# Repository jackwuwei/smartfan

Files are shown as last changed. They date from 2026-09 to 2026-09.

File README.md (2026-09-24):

# 19" 2U Smart Temperature-Controlled Rack Fan (DIY)

**English** | [简体中文](README.zh-CN.md)

A 19-inch 2U rack-mount fan panel for network/server cabinets: three 80mm PWM fans automatically adjust their speed based on the temperature inside the cabinet. **The temperature control loop runs on the Arduino, so cooling keeps working even when the network is down.** A front-panel OLED + rotary knob provide local control, and WiFi/MQTT connects it to Home Assistant, which can in turn bridge it to Apple HomeKit. The panel is 3D printed, and every module connects **directly to the Arduino** with dupont wires (no soldering, no resistors).

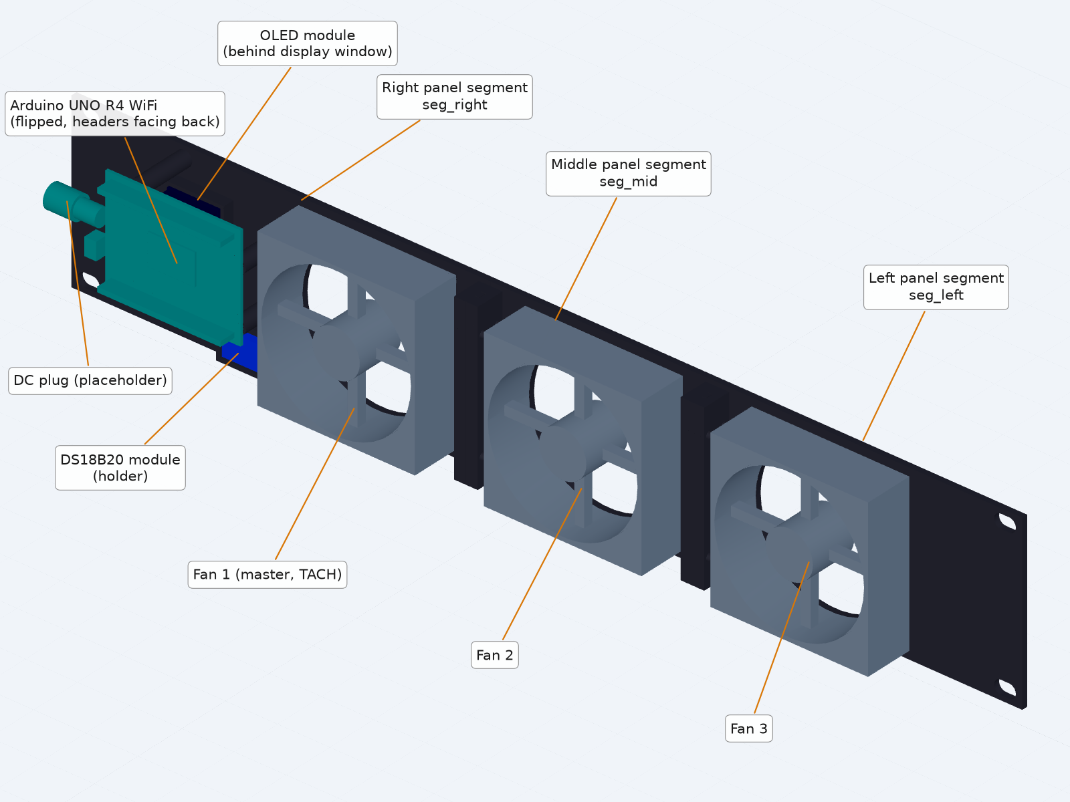
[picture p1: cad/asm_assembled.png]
Assembled


### Photos

<p align="center">
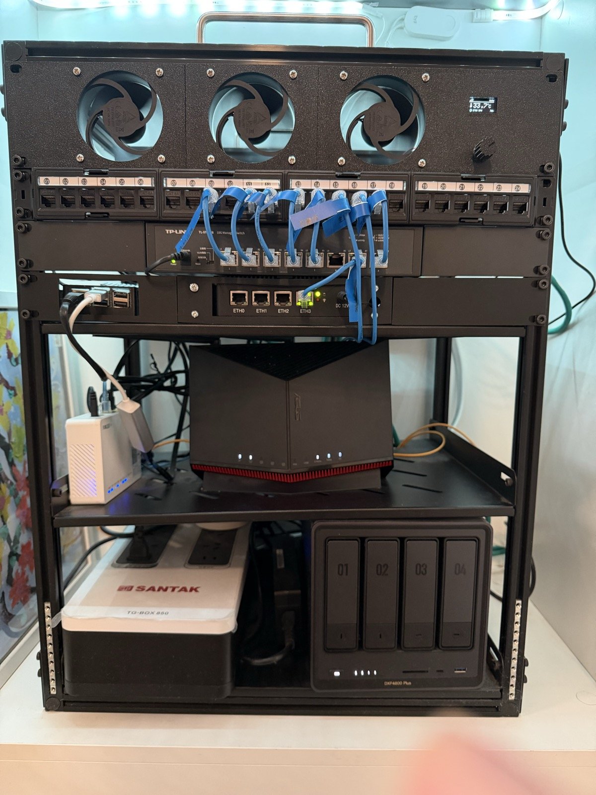
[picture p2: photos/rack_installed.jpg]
Installed at the top of a network cabinet
  
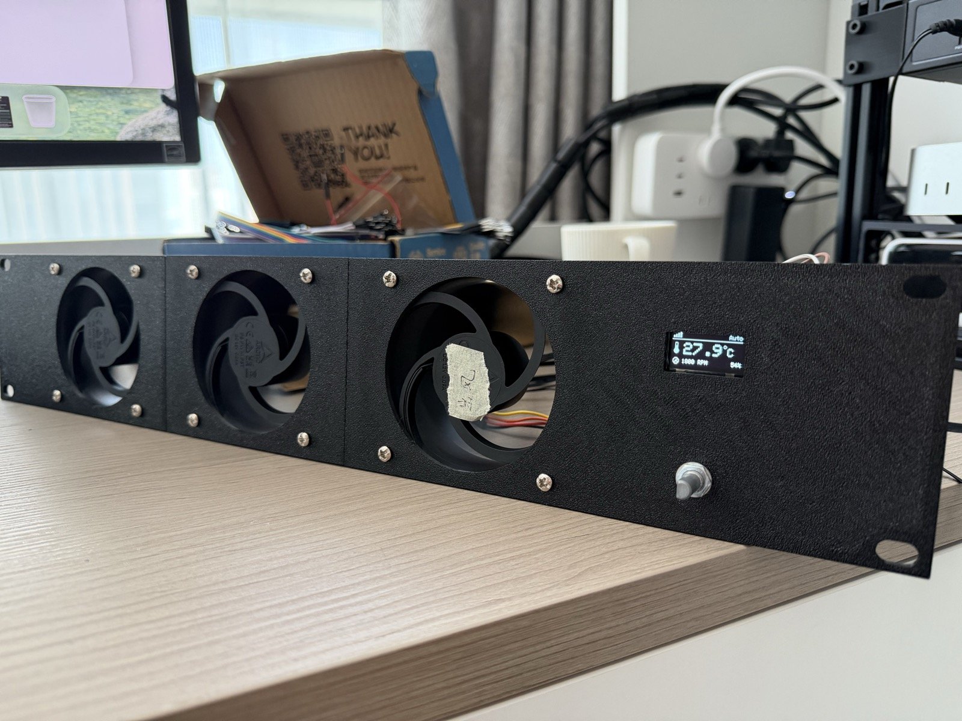
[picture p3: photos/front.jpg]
Front panel: 3 fans, OLED and knob
  
</p>
<p align="center"><i>Left: installed at the top of a home network cabinet. Right: front panel — OLED shows temperature, mode, master fan RPM and duty.</i></p>

<p align="center">
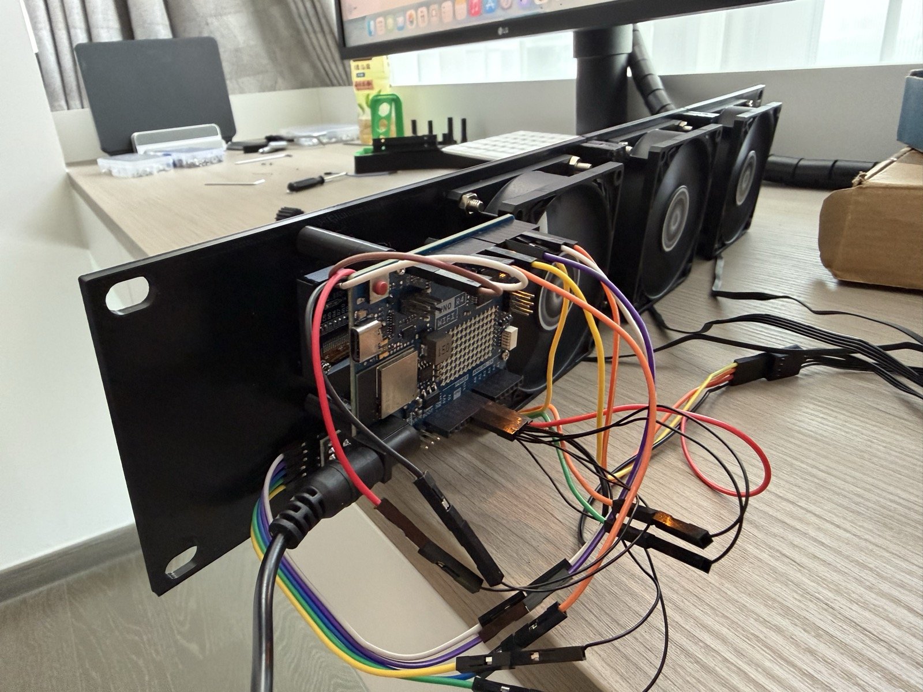
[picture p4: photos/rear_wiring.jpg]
Rear view: flipped Arduino with dupont wires plugged straight into the headers
  
</p>
<p align="center"><i>Rear: the Arduino is mounted flipped so every module plugs straight into its headers with dupont wires (no breadboard, no soldering).</i></p>

---

## 1. Bill of Materials

### 1.1 Electronics

| Part | Spec | Qty | Approx. price (US) | Link (US) |
|---|---|---|---|---|
| Arduino UNO R4 WiFi | Must be the **WiFi** version (ABX00087) | 1 | $27.50 | [Amazon](https://www.amazon.com/Arduino-UNO-WiFi-ABX00087-Bluetooth/dp/B0C8V88Z9D) |
| Arctic P8 PWM PST fan | 8025, 4-pin PWM, 0.14A, stops at 0% PWM (**not** the "CO" variant) | 3 | ~$9 each | [Amazon](https://www.amazon.com/ARCTIC-P8-PWM-PST-Pressure-optimised/dp/B07WWKF96F) |
| 4-pin male-to-female fan extension cable | 2.54mm, ~300mm / 12" (master fan → Arduino headers) | 1 | ~$8 (2-pack) | [Amazon](https://www.amazon.com/Cable-Matters-2-Pack-4-Pin-Extension/dp/B07FK5H679) |
| 12V DC power adapter | 12V 2A, 5.5×2.1mm, center positive | 1 | ~$9 | [Amazon](https://www.amazon.com/Power-Supply-5-5x2-1mm-Plug-White/dp/B09J267K2P) |
| DS18B20 temperature module | Onboard 4.7k pull-up | 1 | ~$7 (3-pack) | [Amazon](https://www.amazon.com/DS18B20-Temperature-Measurement-Arduino-Starter/dp/B0786CZCYJ) |
| 0.96" OLED | SSD1306, 128×64, 4-pin I2C | 1 | ~$7 | [Amazon](https://www.amazon.com/HiLetgo-Adafruit-Beaglebones-Raspberry-Optional/dp/B076DYCWC8) |
| KY-040 rotary encoder | Threaded bushing + nut + push button | 1 | ~$9 (8-pack) | [Amazon](https://www.amazon.com/WGCD-KY-040-Degree-Encoder-Arduino/dp/B07B68H6R8) |
| **1-to-3 dupont splitter cable** | 2.54mm, one male end → three female ends; one for 5V, one for GND | 2 | ~$7 (pack) | [Amazon search](https://www.amazon.com/s?k=dupont+jumper+wire+splitter+1+male+to+3+female) |
| Dupont wires | 20cm, M-F / M-M / F-F assortment, for signals | several | ~$7 (120 pcs) | [Amazon](https://www.amazon.com/Elegoo-EL-CP-004-Multicolored-Breadboard-arduino/dp/B01EV70C78) |

> Total ≈ US$110 (Amazon prices vary; most small parts only come in multi-packs). Three fans at full speed draw about 0.4A @ 12V and the whole unit ~0.7A, so a 12V 2A adapter is plenty. The links are examples — any part matching the spec column works. Buying in China? [README.zh-CN.md](README.zh-CN.md) lists Taobao links.
>
> ⚠ The printed mounts were sized on the original (Taobao) modules: DS18B20 PCB 28.2×13mm, OLED M2 holes 21×21.5mm apart, encoder bushing Ø6.8mm. Module footprints vary between sellers — check yours, and adjust `SENS_*`/`MOD_*`, `OLED_HOLE_*` and `ENC_HOLE_D` in `cad/rack_fan_2u.py` if needed (see `cad/README.md`).

### 1.2 Printed parts (PETG, Bambu P1S)

The 482.6mm panel is wider than the 256mm print bed, so it is split into 3 segments joined with M3 screws. STLs are in `cad/stl/`.

| Part | Contents | Orientation |
|---|---|---|
| `seg_left.stl` (155mm) | Fan 3 + left rack ear | Front face down |
| `seg_mid.stl` (117mm) | Fan 2 | Front face down |
| `seg_right.stl` (215mm) | Fan 1 (master) + control area (OLED window, knob hole, Arduino standoffs, DS18B20 holder) + right rack ear | Front face down |
| `encoder_knob.stl` | Knob (D-shaped bore, press-fits a 6mm shaft) | Top face down |

Print settings: 0.2mm layers / 4 walls / 30–40% gyroid, essentially no supports. PLA softens with heat — use PETG.

### 1.3 Fasteners

| Use | Spec | Qty |
|---|---|---|
| Joining segments | M3×16 + nut | 8 |
| Fans → panel | M4 | 12 |
| Arduino → standoffs | M2×8 self-tapping | 4 |
| OLED → standoffs | M2×6 self-tapping | 4 |
| DS18B20 → holder | M2.5×6 self-tapping | 1 |
| Encoder | Nut supplied with the module | 1 |
| Rack mounting | M6 cage nuts + screws | 4 |
| Cable strain relief | Zip ties | several |

---

## 2. Schematic

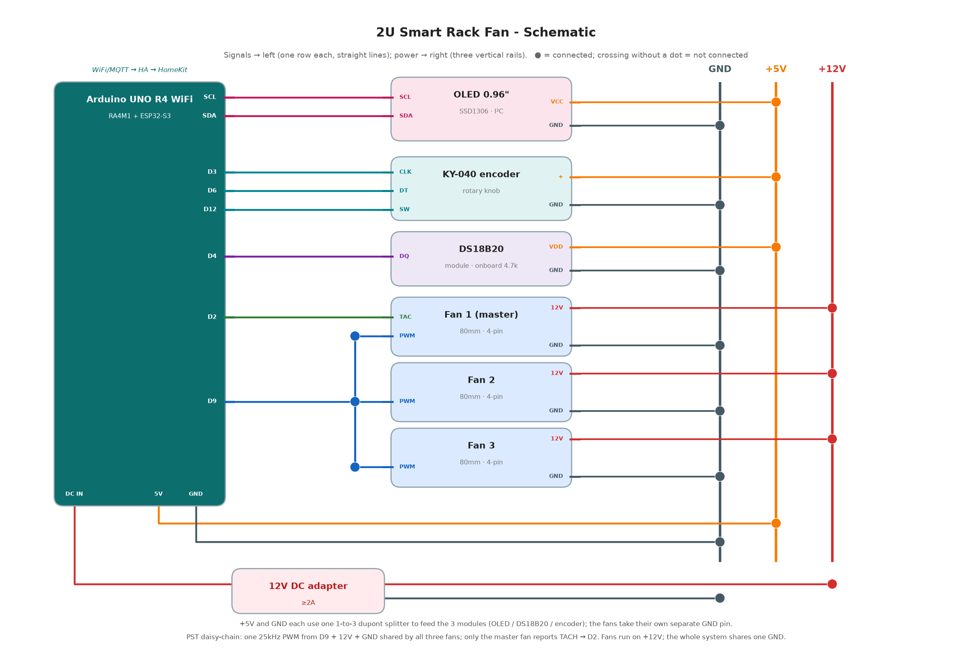
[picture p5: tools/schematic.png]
Wiring schematic


> Signal lines run left to the Arduino; power lines run right to the three power rails (GND / +5V / +12V). ● = connected; a crossing without a dot = not connected.

**Pin assignment (UNO R4 WiFi)**

| Function | Pin | Notes |
|---|---|---|
| Fan PWM | **D9** | 25kHz (core `PwmOut`), drives all 3 fans through the PST daisy chain |
| Fan TACH | **D2** | Master fan only; `INPUT_PULLUP`, interrupt-counted (2 pulses/rev) |
| DS18B20 | **D4** | 1-Wire, module has an onboard 4.7k pull-up |
| OLED | **SDA / SCL** | I2C, address 0x3C |
| KY-040 | **D3 / D6 / D12** | CLK / DT / SW, internal pull-ups; **CLK must be on D3** (on the R4 only D2/D3 support external interrupts, and D2 is taken by TACH) |
| Fan +12V | **VIN** | 12V enters through the onboard DC barrel jack and is taken straight from VIN |

---

## 3. Wiring

**Two 1-to-3 dupont splitters distribute power; everything else plugs straight into the Arduino headers.**

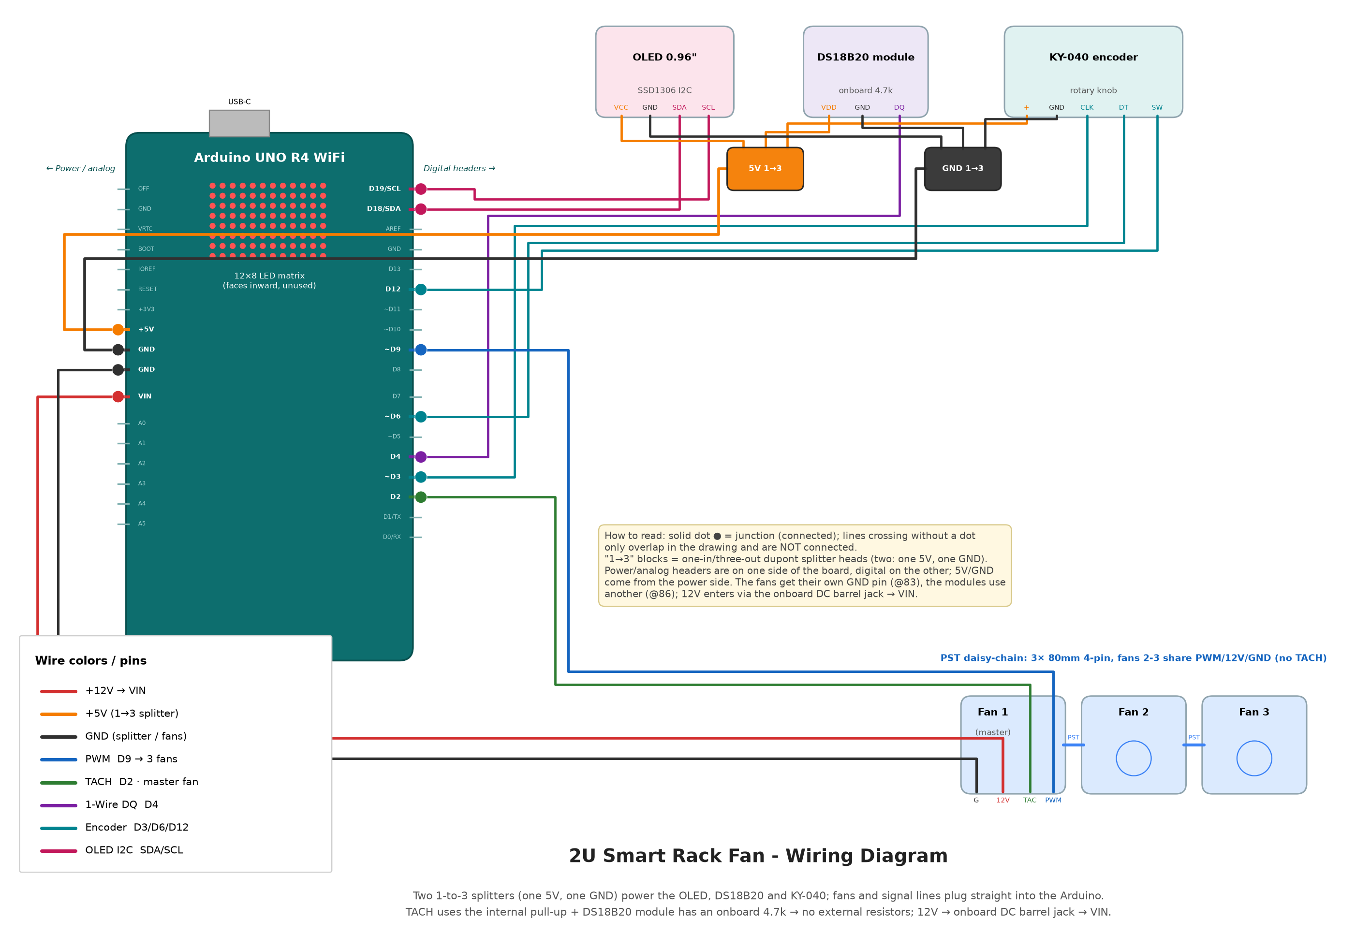
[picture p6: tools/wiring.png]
Wiring diagram


> Colors: red = +12V, orange = +5V, black = GND, blue = PWM, green = TACH, purple = 1-Wire, cyan = encoder, pink = I2C. The two small squares are the 5V / GND 1-to-3 splitters.

### 3.1 Connection table

| Arduino | Connects to | Wire |
|---|---|---|
| DC barrel jack | 12V adapter | — |
| **5V** | OLED VCC / DS18B20 VDD / KY-040 + | 1-to-3 splitter #1 |
| **GND** (pin ②) | OLED GND / DS18B20 GND / KY-040 GND | 1-to-3 splitter #2 |
| **VIN** | Master fan pin 2 (+12V) | 4-pin adapter cable |
| **GND** (pin ①) | Master fan pin 1 (GND) | 4-pin adapter cable |
| **D9** | Master fan pin 4 (PWM) | 4-pin adapter cable |
| **D2** | Master fan pin 3 (TACH) | 4-pin adapter cable |
| **SDA / SCL** | OLED SDA / SCL | Dupont wire |
| **D4** | DS18B20 DQ | Dupont wire |
| **D3 / D6 / D12** | KY-040 CLK / DT / SW | Dupont wire (swap CLK/DT if the rotation direction is reversed) |

- **PST daisy chain**: Fan 1 (master) → Fan 2 → Fan 3, chained through the male/female 4-pin connectors built into the fans. GND / +12V / PWM are shared along the chain; the two downstream fans don't report TACH, so only the master fan's speed can be measured.
- The fan ground and the module ground each use their own GND pin; they are common on the board.

### 3.2 4-pin fan connector pinout

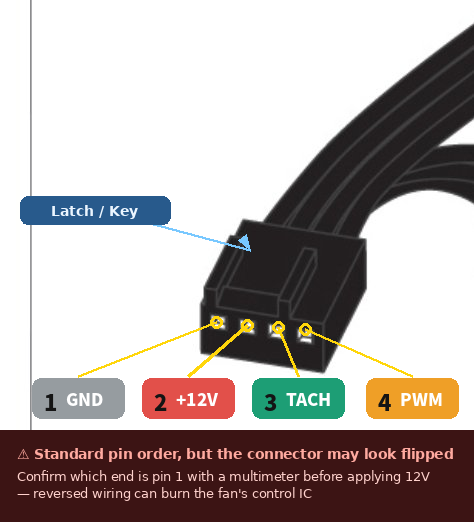
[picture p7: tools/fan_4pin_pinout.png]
4-pin fan pinout


| Pin | Signal | Connects to |
|---|---|---|
| 1 | GND | GND |
| 2 | +12V | VIN |
| 3 | TACH | D2 |
| 4 | PWM | D9 |

> ⚠ Locate pin 1 using the locking tab and confirm with a multimeter before powering up — plugging it in reversed can destroy the fan.

### 3.3 Pre-power-on checklist

- [ ] No short between VIN/GND or 5V/GND; the master fan's 4-pin cable is not reversed.
- [ ] All 3 leads of the 5V splitter go to module positive pins; all 3 leads of the GND splitter go to module grounds.
- [ ] First connect only the master fan and verify speed control and RPM reading, then chain on the other two.

---

## 4. Software Overview

Firmware: `firmware/smartfan/smartfan.ino` (single file, non-blocking main loop).

```mermaid
flowchart TD
    BOOT([Power on]) --> INIT["Init PWM / OLED / knob / TACH"]
    INIT --> RST{"Knob held ≥2s at boot?"}
    RST -->|Yes| CLR["Clear network config"]
    RST -->|No| LOAD
    CLR --> LOAD["Load EEPROM: setpoint / mode / manual %"]
    LOAD --> NET{"Network configured?"}
    NET -->|No| PORTAL["Provisioning portal<br/>Scan WiFi → start AP RackFan-Setup<br/>Show QR on OLED → fill web form → save & reboot"]
    NET -->|Yes| WIFI["Connect WiFi (non-blocking)"]
    WIFI --> LOOP

    subgraph LOOP["loop() main loop"]
        direction TB
        E["Every pass: read knob"]
        S["Every 1s: read temperature + compute RPM → control (compute duty → PWM) → check alarms"]
        D["Every 250ms: refresh OLED"]
        M["Every 2s: publish state over MQTT"]
        R["Every 5s: reconnect WiFi/MQTT if dropped"]
        P["HA command received → update settings and save to EEPROM"]
    end
```

> **Networking is an add-on**: if WiFi/MQTT/HA goes down, only reporting and remote control are affected — temperature sampling and fan control keep running.
>
> **Watchdog**: a ~5.5s hardware watchdog resets the board if the main loop (or the provisioning loop) ever hangs, e.g. the WiFi co-processor stops responding. After a watchdog reset the fans start at 100% and slew down to the curve, so even repeated resets keep the cabinet cooled.

### 4.1 Control algorithm

**Fan curve** (shifts with the setpoint Tset, default 35°C):

- `T ≤ Tset−10°C` → 20%; `T ≥ Tset+6°C` → 100%; linear in between
- With defaults: 25°C→20%, 30°C→45%, 35°C→70%, ≥41°C→100%
- Duty changes by at most 5% per second to avoid abrupt jumps

**Four modes**

| Mode | Duty |
|---|---|
| Auto | Follows the curve |
| Silent | Follows the curve, capped at 60% |
| Manual | Fixed manual value |
| Turbo | 100% |

**Safety (takes priority over the mode)**

- Sensor unreadable / out of range, or temperature ≥ 60°C → forced 100% + alarm
- Duty >25% but master fan <60 RPM → stall alarm
- Power off (turned off from HA) → 0%, fans stop. ⚠ Power off overrides the safety rules above: while off, the fans stay stopped even on over-temperature or sensor failure (the alarm is still raised and reported to HA)
- On alarm the whole OLED screen blinks

### 4.2 Knob and display

| Action | Effect |
|---|---|
| Rotate | Adjust setpoint (±1°C, 25–55); in Manual mode, adjust fan % (±5) |
| Short press | Cycle the display page: temperature → setpoint → fan % → mode (display only — what rotating adjusts depends on the mode, see above) |
| Long press (≥0.8s) | Change mode: Auto → Manual → Silent → Turbo |
| Hold 2s at power-on | Re-run WiFi provisioning |

OLED: top bar shows WiFi signal + mode, the middle shows the temperature in large digits, the bottom shows master fan RPM + duty. While turning the knob, the middle temporarily shows the value being adjusted.

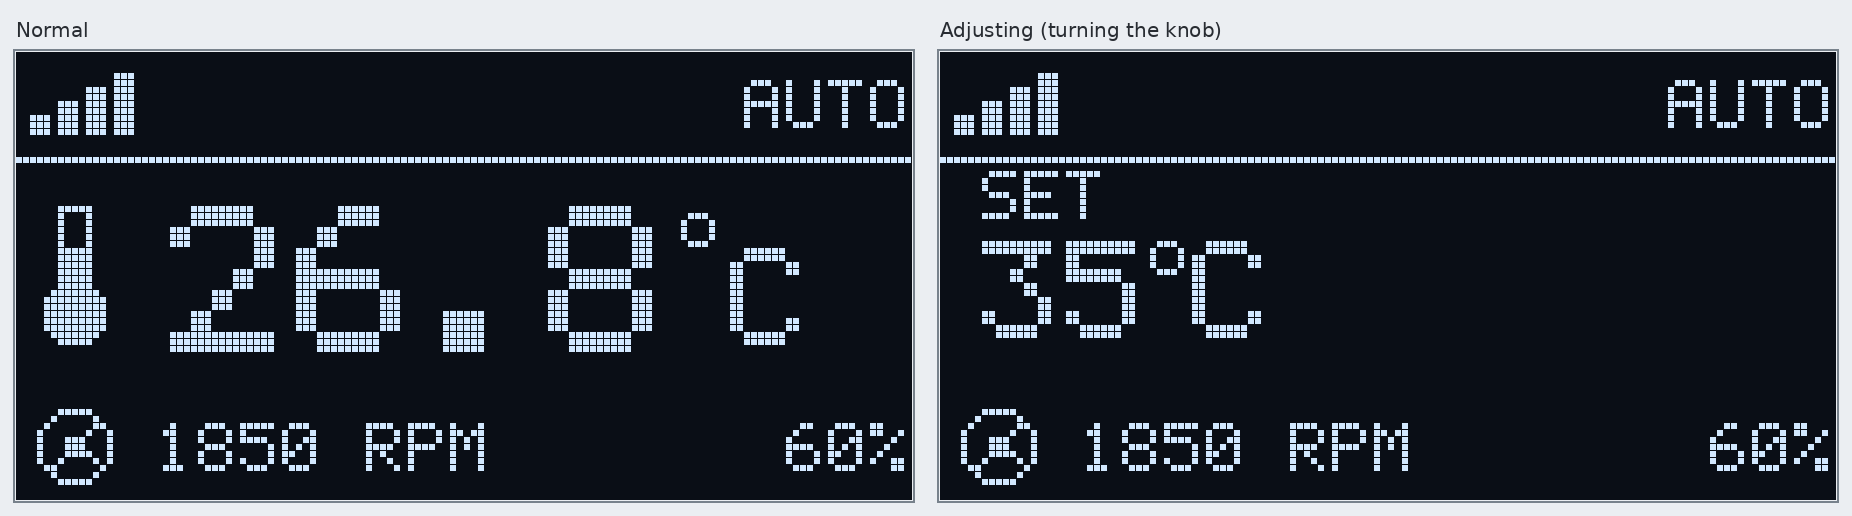
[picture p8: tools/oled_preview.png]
OLED layout


Setpoint, mode and manual % are stored in EEPROM (survive power loss) and sync both ways with HA.

### 4.3 WiFi provisioning

1. On first boot (or when holding the knob for 2s at power-on), the OLED shows a QR code.
2. Scan it with your phone to join the `RackFan-Setup` hotspot (password `configme123`). The setup page usually pops up automatically; if not, open `192.168.4.1`.
3. Pick your WiFi from the list (**2.4GHz only**) and enter its password, then the MQTT host/port/credentials and device ID (default `rackfan01`) → save, and the device reboots automatically.

Temperature control keeps running while the setup portal is open (the OLED just shows the QR code instead of the status screen).

> The setup hotspot password is a public default. It only matters while the portal is open, but anyone nearby could join during that window — change `AP_PASS` at the top of the `.ino` before flashing if that concerns you. WiFi/MQTT credentials are stored in the board's EEPROM, and MQTT runs unencrypted on port 1883, so keep the broker on a trusted LAN.

### 4.4 Home Assistant / HomeKit

1. In HA, install the **Mosquitto broker** and create an MQTT user (enter this user during provisioning), then add the **MQTT** integration (leave the discovery prefix as `homeassistant`).
2. Once the device is online, **Smart Rack Fan** appears automatically with: `climate` (thermostat + mode presets), `fan` (on/off + speed), `sensor` (temperature, RPM), `binary_sensor` (alarm).
3. Add the **HomeKit Bridge** integration and include the `climate` entity → pair it in the Apple Home app by scanning the code, and you can control it with Siri.

MQTT topics are `rackfan/<device ID>/<item>/state` (reports) and `.../<item>/set` (commands). Report-only items: `temp`, `rpm`, `action`, `alarm`, plus `rackfan/<device ID>/avail` (`online` / `offline`, retained; `offline` is the broker-published last-will, so HA shows the entities as unavailable when the device drops off); controllable items: `power`, `hvac/mode` (cool/off), `set` (target temperature 25–55), `mode` (Auto/Manual/Silent/Turbo), `pct` (manual %). For debugging, subscribe to `rackfan/rackfan01/#`. If you'd rather not use auto-discovery, configure it manually with `homeassistant/rack_fan.yaml`.

---

## 5. Assembly

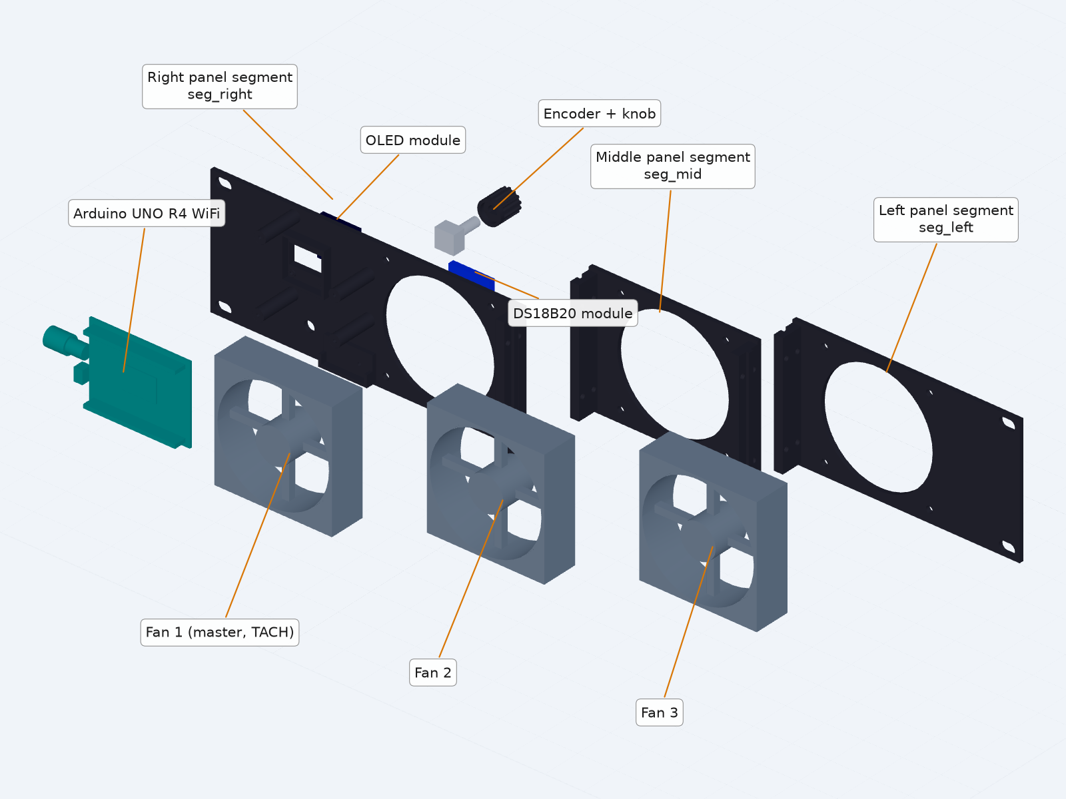
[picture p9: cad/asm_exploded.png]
Exploded view


1. **Join the panel**: slot the three segments together by their tongue-and-groove joints; 4 × M3×16 + nuts per seam.
2. **Mount the fans**: fans go behind the panel, fixed with M4 screws. This unit **exhausts air out of the cabinet**: the airflow arrow points forward (toward the panel), so the cabinet needs a cool-air intake elsewhere.
3. **Mount the OLED**: align the glass with the display window and screw it onto the four corner standoffs with 4 × M2×6 self-tapping screws, pins facing backward.
4. **Mount the Arduino**: 4 × M2×8 self-tapping screws into the standoffs. ⚠ **Component side / headers face backward** (so dupont wires fit), and **USB/DC ports face right** (toward the rack ear, so the 12V plug has room).
5. **Mount the encoder + DS18B20**: pass the encoder bushing through the panel hole, tighten with its nut, then press on the knob; slide the DS18B20 into its holder and fix it with 1 × M2.5 self-tapping screw.
6. **Wire it up**: follow Section 3; secure the adapter cable, splitters and power lead with zip ties.
7. **Rack it**: M6 screws through the oval slots on both sides. Plug in 12V and provision as in 4.3.

---

## 6. Flashing and Development

- **Flashing**: in the Arduino IDE install the `Arduino UNO R4 Boards` core, then the libraries `ArduinoMqttClient`, `ArduinoJson` (v6 or v7), `OneWire`, `DallasTemperature`, `Adafruit GFX Library`, `Adafruit SSD1306`, `QRCode` (Richard Moore). Close the Serial Monitor before uploading.
- Tunables at the top of the `.ino`: `DEBUG_NO_HW` must be 0 (1 = simulated temperature, for bench testing only); `USE_PWMOUT_25K` = 1 outputs 25kHz, 0 falls back to analogWrite (~490Hz, audible whine); `OLED_ADDR`; control parameters; `AP_PASS`.
- **Bring-up order**: provisioning → master fan speed control/RPM → chain all 3 fans → unplug the DS18B20 to verify forced 100% → knob/OLED → disconnect the network to verify it still follows the curve.
- **CAD**: `cad/rack_fan_2u.py` is the single source of parameters; see [cad/README.md](cad/README.md) for the parameter reference and build commands.
- **Regenerating images**: `python3 tools/gen_schematic.py` (schematic), `gen_breadboard.py` (wiring diagram), `gen_oled_preview.py` (OLED preview). Requires `matplotlib` and `Pillow`.

```
.
├── README.md                  This document
├── firmware/smartfan/         Firmware
├── homeassistant/             Manual HA YAML (fallback)
├── photos/                    Photos of the finished build
├── cad/                       Parametric CAD + STEP; stl/ holds the printable parts
└── tools/                     Scripts and images for the schematic / wiring diagram / OLED preview
```

## License

[MIT](LICENSE) — covers the firmware, scripts, CAD sources and printable models. Build and use at your own risk.

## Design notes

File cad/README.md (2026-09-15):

# CAD sources (build123d, parametric)

**English** | [简体中文](README.zh-CN.md)

The full assembly and every printed part are generated parametrically by these Python scripts. Change a parameter → regenerate → the STEP files (this directory) and STL files (`stl/`) update together.

## 1. File relationships

```
rack_fan_2u.py        main file: all parameters + geometry helpers + full assembly gen_step()
   ├─ seg_left.py     thin wrapper → make_segment() cuts the left segment    (no own parameters)
   ├─ seg_mid.py      thin wrapper → make_segment() cuts the middle segment  (no own parameters)
   ├─ seg_right.py    thin wrapper → make_segment() cuts the right segment   (no own parameters)
   └─ encoder_knob.py standalone knob part with its own parameters; imported into the assembly by the main file
```

- **Printed-part dimensions and hole positions → almost all live in the parameter block at the top of `rack_fan_2u.py`.** The 3 thin wrappers only "cut one piece out of the full assembly" and carry no parameters.
- Any change to `rack_fan_2u.py` means regenerating all 4 printed parts (they import it).
- Only the knob's shaft fit is tuned separately, in `encoder_knob.py`.

## 2. Coordinate system (Z-up)

Origin = **center of the panel front face**. `X` = width (+ is right), `Z` = height (+ is up), `Y` = depth (+Y points behind the panel).
CAD Viewer is Z-up as well. `rack_fan_2u.step` is the **full assembly** (including fan/Arduino placeholders), for viewing only — it is **not printed**.

## 3. How to generate

Each script exposes a `gen_step()` that returns a build123d shape. Run all commands from `cad/`.

### Option A: with the `cad` agent skill

If you use the `cad` agent skill (with its venv set up):

```bash
source ~/.agents/skills/cad/.venv/bin/activate
SKILL=~/.agents/skills/cad/scripts

# Full assembly (for viewing)
python $SKILL/step rack_fan_2u.py

# Individual printed parts: STEP (this directory) + STL (into stl/)
python $SKILL/step seg_right.py        --force --stl stl/seg_right.stl
python $SKILL/step seg_left.py         --force --stl stl/seg_left.stl
python $SKILL/step seg_mid.py          --force --stl stl/seg_mid.stl
python $SKILL/step encoder_knob.py     --force --stl stl/encoder_knob.stl
```

### Option B: plain build123d

```bash
pip install build123d
```

Then, from `cad/`:

```python
import importlib
from build123d import export_step, export_stl

# Printed parts: STEP + STL
for name in ["seg_left", "seg_mid", "seg_right", "encoder_knob"]:
    shape = importlib.import_module(name).gen_step()
    export_step(shape, f"{name}.step")
    export_stl(shape, f"stl/{name}.stl")

# Full assembly (for viewing only, no STL needed)
import rack_fan_2u
export_step(rack_fan_2u.gen_step(), "rack_fan_2u.step")
```

> After changing shared parameters in `rack_fan_2u.py`, **regenerate all 4 printed parts**; if you only changed `encoder_knob.py`, just regenerate the knob (and the assembly).

## 4. `rack_fan_2u.py` parameters (all at the top of the file, in mm)

### Panel / rack
| Parameter | Default | Meaning / effect of changing |
|---|---|---|
| `PANEL_W, PANEL_T, PANEL_H` | 482.6, 3.0, 88.1 | 19" 2U panel width / thickness / height (EIA-310; don't change width or height) |
| `RACK_HOLE_DX` | 465.1/2 | Half the distance between left and right rack hole centers |
| `RACK_HOLE_Z` | 38.1 | Rack hole Z per side (symmetric ±38.1) |
| `RACK_SLOT_LEN, RACK_SLOT_H` | 11.0, 7.0 | Rack oblong slot X length / Z height (length − height = ±2mm side-to-side play, M6) |

### Fans
| Parameter | Default | Meaning / effect of changing |
|---|---|---|
| `FAN` | 80.0 | Fan size (8025) |
| `FAN_BORE_D` | 76.0 | Panel air inlet cutout diameter |
| `FAN_HOLE_PITCH` | 71.5 | Square spacing of the 4 M4 screw holes |
| `FAN_HOLE_D` | 4.5 | M4 clearance hole diameter |
| `FAN_DEPTH` | 25.0 | Fan thickness (placeholder only) |
| `FAN_CX` | [-144, -29, 86] | **X centers of the 3 fans.** Changing this moves the whole layout; together with `CTRL_CX` it sets the 4 evenly spaced columns |

### Control column: OLED window / knob / Arduino / connectors
| Parameter | Default | Meaning / effect of changing |
|---|---|---|
| `CTRL_CX` | 174.0 | **Control column X center** (the OLED window is centered on it). Note that `ARD_CX`, `ENC_CX` and `SENS_CX` are set separately — update them as needed when changing `CTRL_CX` |
| `ARD_CX` | 165.0 | **Arduino X center** (9 left of `CTRL_CX`): clearance for the DC jack/plug on the right; **any further left hits fan 1 (master)** (left posts ≈ X133, fan 1 right edge X126) |
| `ARD_CZ` | 14.0 | Arduino Z center (mounted flipped; onboard matrix faces inward and is unused, so no window alignment needed) |
| `OLED_CZ` | 14.0 | OLED window + module Z center |
| `OLED_WIN_W, OLED_WIN_H` | 25.0, 13.5 | OLED window in the panel; window center `OLED_WIN_CZ` = `OLED_CZ` + 0.75 |
| `OLED_MOD_W/_T/_H` | 26.0, 5.0, 26.0 | OLED module PCB outline (placeholder + sets the size of the rear pocket) |
| `OLED_PIN_H` | 8.5 | OLED 4-pin header protrusion (wires exit toward +Y) |
| `OLED_HOLE_DX` | 10.5 | X of the OLED corner holes relative to board center (±10.5; measured 25×25 board, 2.0 from each side) |
| `OLED_HOLE_DZ_TOP, _BOT` | 11.0, -10.5 | Z of top/bottom holes relative to board center (top 1.5 from top edge, bottom 2.0 from bottom edge) |
| `OLED_STANDOFF_H` | 2.0 | Height of the 4 short OLED posts (glass close to the window; tune to the actual glass height) |
| `OLED_STANDOFF_D` | 4.5 | OLED post outer diameter (M2) |
| `OLED_PILOT_D, OLED_PILOT_DEPTH` | 2.0, 4.0 | M2 self-tap pilot hole in the OLED post tops (may extend into the panel) |
| `ENC_CX, ENC_CZ` | 174.0, -26.0 | Encoder (knob/shaft) center, below the OLED window (moved down so the KY-040 pins clear the Arduino posts) |
| `ENC_HOLE_D` | 7.2 | Clearance hole ⌀7.2 for the encoder's threaded bushing |
| `ARD_W, ARD_T, ARD_L` | 68.6, 1.6, 53.4 | UNO R4 board width / thickness / length (placeholder) |
| `ARD_STANDOFF_H` | 28.0 | Arduino post height: flipped, the solder side faces the panel and must clear the OLED module + pins/wires in front |
| `HDR_H` | 8.5 | Arduino female header height (faces backward when flipped; placeholder, sets the dupont-wire clearance) |
| `STANDOFF_D` | 8.0 | Arduino post outer diameter Ø8 |
| `ARD_PILOT_D, ARD_PILOT_DEPTH` | 2.0, 8.0 | **M2 self-tap pilot holes in the tops** of the 4 short Arduino posts (board holes Ø3.2 take M2) |
| `ARD_HOLES` | see file | **(x, z) of the 4 mounting holes relative to board center.** Currently the **flipped** version (component side / female headers toward +Y at the rear, USB/DC short edge still toward +X). If you change the board orientation, the hole positions must flip with it (see §6). |
| `DC_JACK_D/LEN`, `DC_PLUG_D/LEN`, `USB_*`, `CONN_DC_Z/USB_Z` | see file | Placeholders for the DC barrel jack / representative straight plug / USB-C on the port edge, **only for checking plug clearance** — not structural |

> ⚠️ **Two key orientation constraints**: (1) component side / female headers face **+Y (rear)** — otherwise there is no room for dupont wires; (2) the USB/DC short edge faces **+X (toward the panel's open right end)** — otherwise the DC plug can't go straight into the barrel jack. See the root `README.md` → "Assembly", step 4.

> 🔌 **Direct wiring**: the OLED/DS18B20/KY-040 connect directly to the Arduino via two 1-to-3 dupont splitter cables (one for 5V, one for GND); there is no breakout board, tray or other carrier on the panel.

### Sensor / cabling
| Parameter | Default | Meaning |
|---|---|---|
| `SENS_CX, SENS_CZ` | 145.0, -33.0 | DS18B20 module cradle center (free space below the control area) |
| `MOD_W, MOD_H, MOD_T` | 28.2, 13.0, 4.0 | DS18B20 PCB module outline (measured; sets the cradle size) |
| `SENS_HOLE_DX` | 6.4 | Sensor board mounting hole distance from the left edge (vertically centered); M2.5 self-tap hole in the cradle base |
| `SENS_PILOT_D` | 2.2 | M2.5 self-tap pilot hole diameter |
| `VENT_ZS` | () | Control-area vent slots (empty = none; if added, keep clear of the ⌀16 knob at `ENC_CZ`) |
| `CABLE_TIE_X` | () | Cable-tie holes along the bottom edge (empty = none) |

### Segmented printing + M3 joints
| Parameter | Default | Meaning / effect of changing |
|---|---|---|
| `SEAM1, SEAM2` | -86.5, 28.5 | **X of the two seams.** Must fall in the solid area between fans, and each segment must be ≤ 256 wide (P1S bed) |
| `WALL_T` | 6.0 | Joint wall thickness per side (X) |
| `WALL_Y0, WALL_Y1` | 3.0, 18.0 | Y range of the joint walls behind the panel (15mm deep) |
| `WALL_Z` | 84.0 | Joint wall height (nearly full height) |
| `GROOVE_W, GROOVE_D` | 4.0, 2.2 | Alignment tongue/groove width in Y / depth in X (tongue clearance is applied automatically) |
| `BOLT_YS, BOLT_ZS` | (6,15), (-28,28) | Y and Z positions of the 4 M3 bolts per seam (two rows, either side of the tongue/groove) |
| `M3_CLEAR_R` | 1.75 | M3 clearance hole radius (⌀3.5) |

## 5. `encoder_knob.py` parameters (standalone knob)

| Parameter | Default | Meaning / effect of changing |
|---|---|---|
| `SHAFT_D` | 6.0 | Encoder **shaft diameter** (round). Match your part |
| `SHAFT_FLAT_ACROSS` | 4.8 | D-shaft thickness **from the flat to the opposite side**. Match your part |
| `SHAFT_EXPOSED` | 14.0 | Shaft length proud of the panel front face with the nut tightened. Sets the bore depth and knob height |
| `FIT_CLEAR` | 0.3 | Bore print clearance (0.2~0.4; increase if too tight) |
| `TIP_CLEAR` | 0.5 | Gap between shaft tip and bore bottom, so the knob seats on the panel rather than on the shaft tip |
| `NUT_BORE_D, NUT_BORE_H` | 12.2, 3.0 | Bottom counterbore diameter / depth that clears the M7 mounting nut (KY-040 has no washer) |
| `KNOB_D` | 16.0 | Knob outer diameter (minimum set by `NUT_BORE_D`; wall around the counterbore ≈ 1.9mm) |
| `BORE_DEPTH` | 14.5 (derived) | Bore depth from the bottom face = `SHAFT_EXPOSED` + `TIP_CLEAR` |
| `TOP_WALL` | 2.5 | Top wall thickness above the bore (1.5mm solid remains under the indicator line) |
| `KNOB_H` | 17.0 (derived) | Knob height = `BORE_DEPTH` + `TOP_WALL` |
| `N_FLUTE, FLUTE_D` | 14, 2.2 | Number of side grip flutes / flute diameter (cut only above the counterbore) |
| `IND_W, IND_DEPTH` | 1.4, 1.0 | Top indicator line width / depth |

> If you switch to a different encoder, mainly check `SHAFT_D` / `SHAFT_FLAT_ACROSS` (round diameter and D-flat) and `SHAFT_EXPOSED`; if the knob won't press on, increase `FIT_CLEAR`.

## 6. Change-coupling reminders

1. **Moving the control column**: if you change `CTRL_CX`, update `ENC_CX` (defaults to the same 174) and `SENS_CX` (independent, 145) as needed, and check that the right rack slot (X = `RACK_HOLE_DX` ≈ 232.6) isn't hit.
2. **Arduino mounting orientation**: in `gen_step` the Arduino is flipped with `Rot(180,0,0)` (component side / female headers toward +Y at the rear, solder side toward the panel), and `ARD_HOLES` is flipped to match. That is why the front display is an **OLED** (`OLED_*` parameters + `Adafruit_SSD1306` in the firmware) instead of the onboard matrix. If you change the orientation, change all of these together.
   - When flipped, the posts must be tall enough (`ARD_STANDOFF_H`) to clear the OLED + pins in front — the female headers face backward, so dupont wires plug in directly.
3. **Seams**: `SEAM1/SEAM2` must fall in the solid area between fans, and each segment must be ≤ 256mm.
4. After any change, always **regenerate and visually inspect in the viewer** (especially hole positions and clearances) — passing deterministic checks doesn't mean nothing collides.

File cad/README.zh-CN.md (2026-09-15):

# CAD 源文件说明(build123d,参数化)

[English](README.md) | **简体中文**

整机与所有打印件都由这些 Python 脚本参数化生成。改参数 → 重新生成 → STEP(本目录)/ STL(`stl/`)一起更新。

## 1. 文件关系

```
rack_fan_2u.py        主文件:全部参数 + 几何函数 + 整机装配 gen_step()
   ├─ seg_left.py     薄包装 → make_segment() 切左段        (无自有参数)
   ├─ seg_mid.py      薄包装 → make_segment() 切中段        (无自有参数)
   ├─ seg_right.py    薄包装 → make_segment() 切右段        (无自有参数)
   └─ encoder_knob.py 独立旋钮件,自带一套参数;被主文件 import 进装配
```

- **改打印件的尺寸/孔位 → 基本都在 `rack_fan_2u.py` 顶部参数区。** 3 个薄包装文件只是"从整机里切出某一块",自己不带参数。
- `rack_fan_2u.py` 一改,4 个打印件都要重生成(它们 import 它)。
- 只有旋钮的轴配合在 `encoder_knob.py` 里单独调。

## 2. 坐标系(Z-up)

原点 = **面板前表面中心**。`X`=宽(右为+)、`Z`=高(上为+)、`Y`=深(+Y 指面板后方)。
CAD Viewer 也是 Z-up。`rack_fan_2u.step` 是**整机装配**(含风扇/Arduino 等占位体),只用于看整机、**不打印**。

## 3. 怎么生成

每个脚本都提供 `gen_step()`,返回一个 build123d 形体。所有命令在 `cad/` 下运行。

### 方式 A:用 `cad` agent skill

如果你装了 `cad` agent skill(并配好了它的 venv):

```bash
source ~/.agents/skills/cad/.venv/bin/activate
SKILL=~/.agents/skills/cad/scripts

# 整机装配(看整机用)
python $SKILL/step rack_fan_2u.py

# 单个打印件:生成 STEP(本目录)+ STL(放进 stl/)
python $SKILL/step seg_right.py        --force --stl stl/seg_right.stl
python $SKILL/step seg_left.py         --force --stl stl/seg_left.stl
python $SKILL/step seg_mid.py          --force --stl stl/seg_mid.stl
python $SKILL/step encoder_knob.py     --force --stl stl/encoder_knob.stl
```

### 方式 B:直接用 build123d

```bash
pip install build123d
```

然后在 `cad/` 下运行:

```python
import importlib
from build123d import export_step, export_stl

# 打印件:STEP + STL
for name in ["seg_left", "seg_mid", "seg_right", "encoder_knob"]:
    shape = importlib.import_module(name).gen_step()
    export_step(shape, f"{name}.step")
    export_stl(shape, f"stl/{name}.stl")

# 整机装配(仅供查看,不需要 STL)
import rack_fan_2u
export_step(rack_fan_2u.gen_step(), "rack_fan_2u.step")
```

> 改了 `rack_fan_2u.py` 的公共参数后,**4 个打印件都要重新跑**;只改 `encoder_knob.py` 则只重生成旋钮(和整机)。

## 4. `rack_fan_2u.py` 参数(全在文件顶部,mm 单位)

### 面板 / 机架
| 参数 | 默认 | 含义 / 改动影响 |
|---|---|---|
| `PANEL_W, PANEL_T, PANEL_H` | 482.6, 3.0, 88.1 | 19" 2U 面板 宽/厚/高(EIA-310,别动宽高) |
| `RACK_HOLE_DX` | 465.1/2 | 左右机架孔中心距的一半 |
| `RACK_HOLE_Z` | 38.1 | 每侧机架孔 Z(上下对称 ±38.1) |
| `RACK_SLOT_LEN, RACK_SLOT_H` | 11.0, 7.0 | 机架椭圆槽 X 长 / Z 高(长−高=±2mm 横向公差,M6) |

### 风扇
| 参数 | 默认 | 含义 / 改动影响 |
|---|---|---|
| `FAN` | 80.0 | 风扇边长(8025) |
| `FAN_BORE_D` | 76.0 | 面板进风开孔直径 |
| `FAN_HOLE_PITCH` | 71.5 | 4 个 M4 螺孔的方阵边距 |
| `FAN_HOLE_D` | 4.5 | M4 过孔直径 |
| `FAN_DEPTH` | 25.0 | 风扇厚度(仅占位体用) |
| `FAN_CX` | [-144, -29, 86] | **3 个风扇的 X 中心**。改它会动整机布局;与 `CTRL_CX` 一起决定 4 列等边距 |

### 控制列:OLED 窗 / 旋钮 / Arduino / 连接器
| 参数 | 默认 | 含义 / 改动影响 |
|---|---|---|
| `CTRL_CX` | 174.0 | **控制列 X 中心**(OLED 窗绕它)。注意 `ARD_CX`、`ENC_CX`、`SENS_CX` 是单独写的,改 `CTRL_CX` 时按需一起改 |
| `ARD_CX` | 165.0 | **Arduino X 中心**(从 `CTRL_CX` 左移 9):给右侧 DC 桶座/插头让空间;**再左会压到风扇1(主)**(左立柱≈X133,风扇1 右缘 X126) |
| `ARD_CZ` | 14.0 | Arduino Z 中心(翻装,板载点阵朝里不用,不需对窗) |
| `OLED_CZ` | 14.0 | OLED 窗 + 模块 Z 中心 |
| `OLED_WIN_W, OLED_WIN_H` | 25.0, 13.5 | 面板 OLED 开窗;窗中心 `OLED_WIN_CZ`=`OLED_CZ`+0.75 |
| `OLED_MOD_W/_T/_H` | 26.0, 5.0, 26.0 | OLED 模块 PCB 外形(占位 + 决定背面口袋大小) |
| `OLED_PIN_H` | 8.5 | OLED 4 针排针凸出(朝 +Y 走线) |
| `OLED_HOLE_DX` | 10.5 | OLED 4 角孔相对板心的 X(±10.5;实测 25×25 板,距两侧 2.0) |
| `OLED_HOLE_DZ_TOP, _BOT` | 11.0, -10.5 | 顶/底孔相对板心 Z(顶距顶边 1.5、底距底边 2.0) |
| `OLED_STANDOFF_H` | 2.0 | OLED 4 短立柱高(玻璃贴近窗;按实物玻璃高微调) |
| `OLED_STANDOFF_D` | 4.5 | OLED 立柱外径(M2) |
| `OLED_PILOT_D, OLED_PILOT_DEPTH` | 2.0, 4.0 | OLED 柱顶 M2 自攻引导孔(可深入面板) |
| `ENC_CX, ENC_CZ` | 174.0, -26.0 | 编码器(旋钮/轴)中心,在 OLED 窗下方(下移以让 KY-040 排针避开 Arduino 立柱) |
| `ENC_HOLE_D` | 7.2 | 编码器螺纹套筒过孔 ⌀7.2 |
| `ARD_W, ARD_T, ARD_L` | 68.6, 1.6, 53.4 | UNO R4 板 宽/厚/长(占位) |
| `ARD_STANDOFF_H` | 28.0 | Arduino 立柱高:翻装后焊接面朝面板,前方要容下 OLED 模块 + 排针/排线 |
| `HDR_H` | 8.5 | Arduino 母排针高(翻装后朝后;占位用,决定插杜邦线的间隙) |
| `STANDOFF_D` | 8.0 | Arduino 立柱外径 Ø8 |
| `ARD_PILOT_D, ARD_PILOT_DEPTH` | 2.0, 8.0 | Arduino 4 短柱**柱顶 M2 自攻引导孔**(板孔 Ø3.2 配 M2) |
| `ARD_HOLES` | 见文件 | **4 个安装孔相对板心的 (x,z)**。当前是**翻装**版(元件面/母排针朝 +Y 后侧、USB/DC 短边仍朝 +X)。若要改装板朝向,孔位要随之翻转(见 §6)。 |
| `DC_JACK_D/LEN`、`DC_PLUG_D/LEN`、`USB_*`、`CONN_DC_Z/USB_Z` | 见文件 | 接口短边上的 DC 桶座 / 代表性直插头 / USB-C 占位,**仅用于校核直插间隙**,不是结构件 |

> ⚠️ **两个关键朝向约束**:① 元件面/母排针朝 **+Y(后侧)**——才有空间插杜邦线;② USB/DC 短边朝 **+X(面板右开口端)**——才能直插 DC 桶座。详见根目录 `README.zh-CN.md` 装配要点第 4 步。

> 🔌 **模块直连**:OLED/DS18B20/KY-040 用 2 根「1分3」杜邦线(5V/GND 各一)直连 Arduino,面板上无分线板/托盘等承载结构。

### 传感器 / 走线
| 参数 | 默认 | 含义 |
|---|---|---|
| `SENS_CX, SENS_CZ` | 145.0, -33.0 | DS18B20 模块卡座中心(控制区下方空位) |
| `MOD_W, MOD_H, MOD_T` | 28.2, 13.0, 4.0 | DS18B20 PCB 模块外形(实测,决定卡座大小) |
| `SENS_HOLE_DX` | 6.4 | 温度板固定孔距左边缘(上下居中);卡座底板上开 M2.5 自攻孔 |
| `SENS_PILOT_D` | 2.2 | M2.5 自攻引导孔径 |
| `VENT_ZS` | () | 控制区散热缝(留空=不开;若要加须避开旋钮 ⌀16 @ `ENC_CZ`) |
| `CABLE_TIE_X` | () | 底沿扎带孔(留空=不开) |

### 分段打印 + M3 连接
| 参数 | 默认 | 含义 / 改动影响 |
|---|---|---|
| `SEAM1, SEAM2` | -86.5, 28.5 | **两条切缝 X**。必须落在风扇之间的实心区;且每段宽度 ≤ 256(P1S 床) |
| `WALL_T` | 6.0 | 每侧连接壁厚(X 向) |
| `WALL_Y0, WALL_Y1` | 3.0, 18.0 | 连接壁在面板后方的 Y 范围(深 15mm) |
| `WALL_Z` | 84.0 | 连接壁高(近满高) |
| `GROOVE_W, GROOVE_D` | 4.0, 2.2 | 对齐舌槽 Y 向宽 / X 向深(凸舌已自动留间隙) |
| `BOLT_YS, BOLT_ZS` | (6,15),(-28,28) | 每缝 4 颗 M3 的 Y、Z 位置(舌槽上下 × 两排) |
| `M3_CLEAR_R` | 1.75 | M3 过孔半径(⌀3.5) |

## 5. `encoder_knob.py` 参数(独立旋钮)

| 参数 | 默认 | 含义 / 改动影响 |
|---|---|---|
| `SHAFT_D` | 6.0 | 编码器**轴径**(圆)。按实物改 |
| `SHAFT_FLAT_ACROSS` | 4.8 | D 形轴**平面到对边**的厚度。按实物改 |
| `SHAFT_EXPOSED` | 14.0 | 拧好螺母后轴露出面板前表面的长度;决定孔深和旋钮高度 |
| `FIT_CLEAR` | 0.3 | 孔的打印间隙(0.2~0.4 调松紧;偏紧调大) |
| `TIP_CLEAR` | 0.5 | 轴尖到孔底留空,保证旋钮压到面板而不是顶在轴尖上 |
| `NUT_BORE_D, NUT_BORE_H` | 12.2, 3.0 | 底面沉孔 直径 / 深度,让开 M7 固定螺母(KY-040 无垫片) |
| `KNOB_D` | 16.0 | 旋钮外径(下限由 `NUT_BORE_D` 决定;沉孔一圈壁厚 ≈1.9mm) |
| `BORE_DEPTH` | 14.5(派生) | 从底面算起的孔深 = `SHAFT_EXPOSED` + `TIP_CLEAR` |
| `TOP_WALL` | 2.5 | 孔顶壁厚(刻掉指示线后仍留 1.5mm 实体) |
| `KNOB_H` | 17.0(派生) | 旋钮高 = `BORE_DEPTH` + `TOP_WALL` |
| `N_FLUTE, FLUTE_D` | 14, 2.2 | 侧面防滑槽数量 / 单槽直径(只开在沉孔以上) |
| `IND_W, IND_DEPTH` | 1.4, 1.0 | 顶面指示线宽 / 深 |

> 换了别的编码器,主要核对 `SHAFT_D` / `SHAFT_FLAT_ACROSS`(轴的圆径与 D 面)和 `SHAFT_EXPOSED`,压不进就把 `FIT_CLEAR` 调大。

## 6. 改参数的几条联动提醒

1. **控制列整体平移**:`CTRL_CX` 改了,记得 `ENC_CX`(默认同 174)和 `SENS_CX`(独立 145)按需跟着改;并检查右机架槽(X=`RACK_HOLE_DX`≈232.6)不被撞。
2. **Arduino 装板朝向**:`gen_step` 里 Arduino 用 `Rot(180,0,0)` 翻装(元件面/母排针朝 +Y 后侧、焊接面朝面板),`ARD_HOLES` 已配套翻好。前显示因此改用 **OLED**(`OLED_*` 参数 + 固件 `Adafruit_SSD1306`),不再用板载点阵。要动朝向就把这几样一起改。
   - 翻装后立柱必须够高(`ARD_STANDOFF_H`)容下前方 OLED+排针——母排针朝后,杜邦线直接插。
3. **切缝**:`SEAM1/SEAM2` 落在风扇之间实心区,且每段 ≤256mm。
4. 改完务必**重生成并在 Viewer 里目检**(尤其孔位/间隙),deterministic 检查通过不代表没撞。

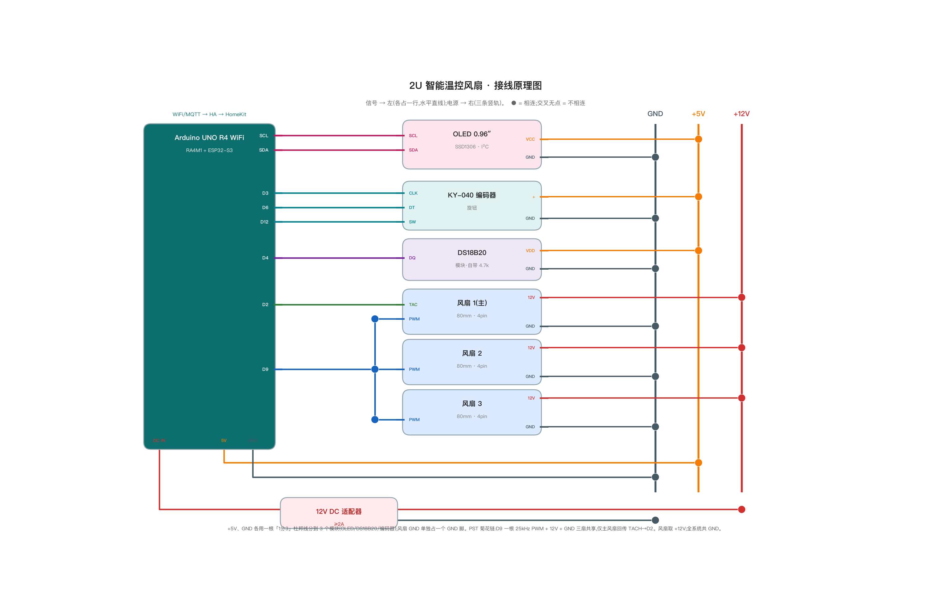
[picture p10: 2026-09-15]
tools/schematic_zh.png

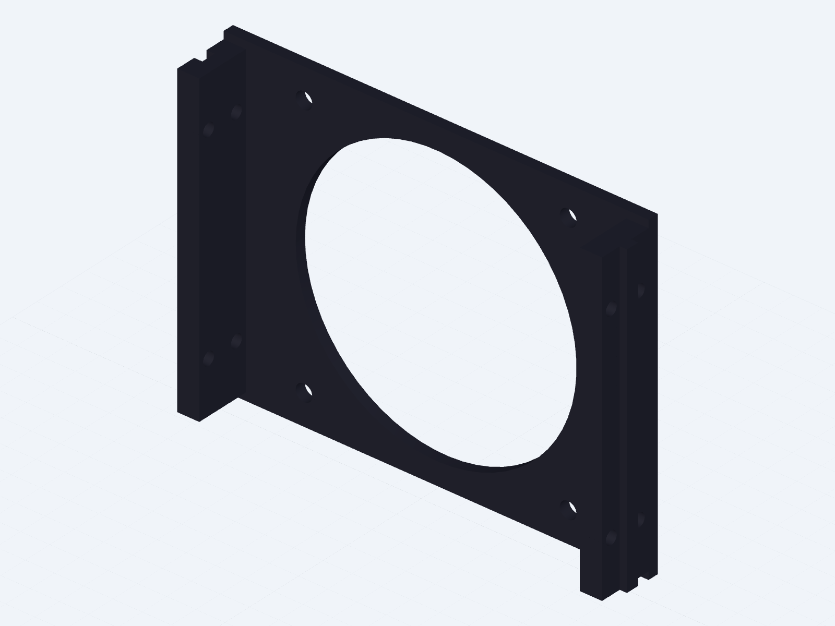
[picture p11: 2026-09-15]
cad/part_seg_mid.png

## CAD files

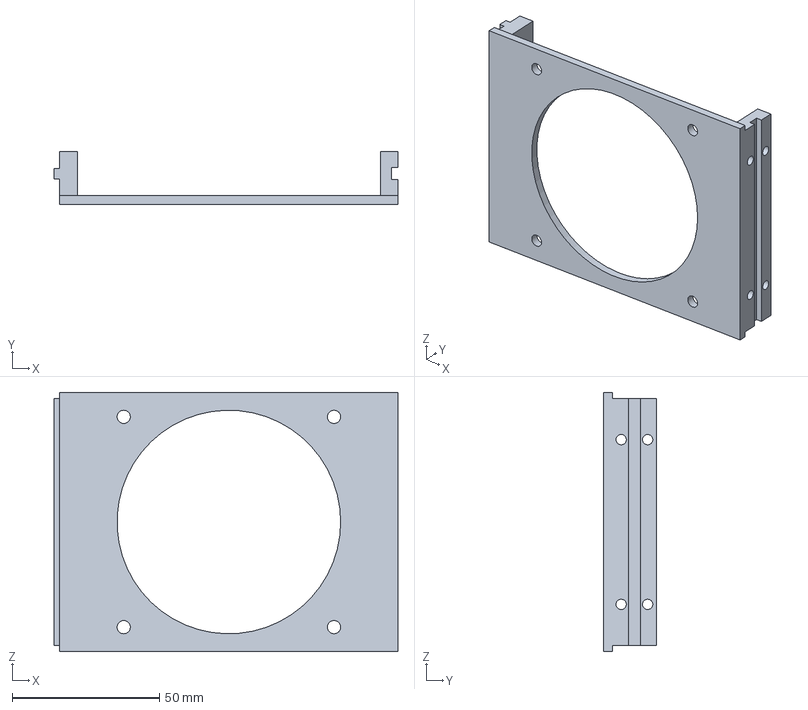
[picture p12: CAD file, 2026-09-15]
cad/seg_mid.step
117.0 x 18.0 x 88.1 mm

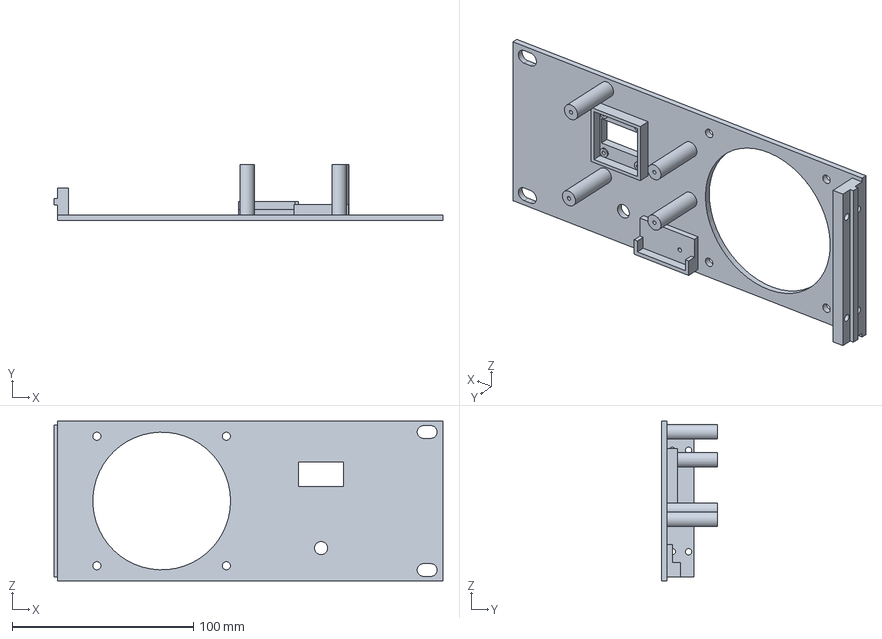
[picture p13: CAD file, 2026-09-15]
cad/seg_right.step
214.8 x 31.0 x 88.1 mm

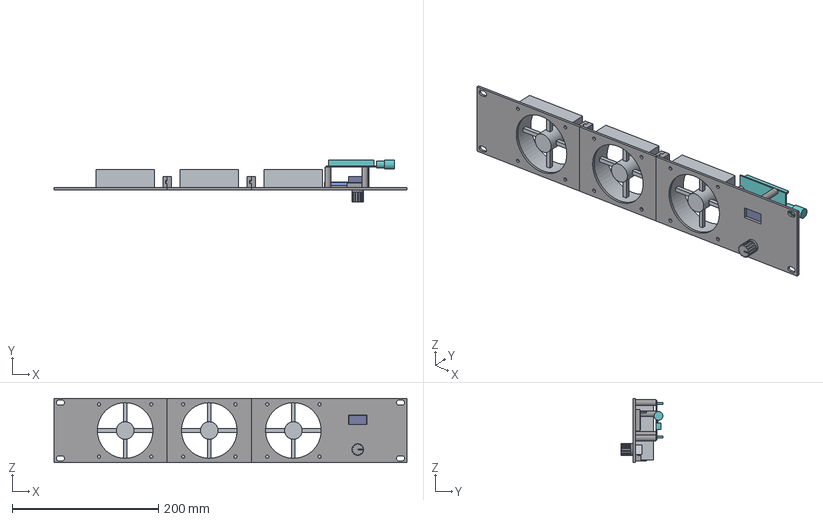
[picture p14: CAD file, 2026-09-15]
cad/rack_fan_2u.step
482.6 x 58.1 x 88.1 mm
seg_left
seg_mid
seg_right
fan_left
fan_mid
fan_right
arduino_uno_r4_wifi
oled_096
rotary_encoder
encoder_knob
ds18b20_module

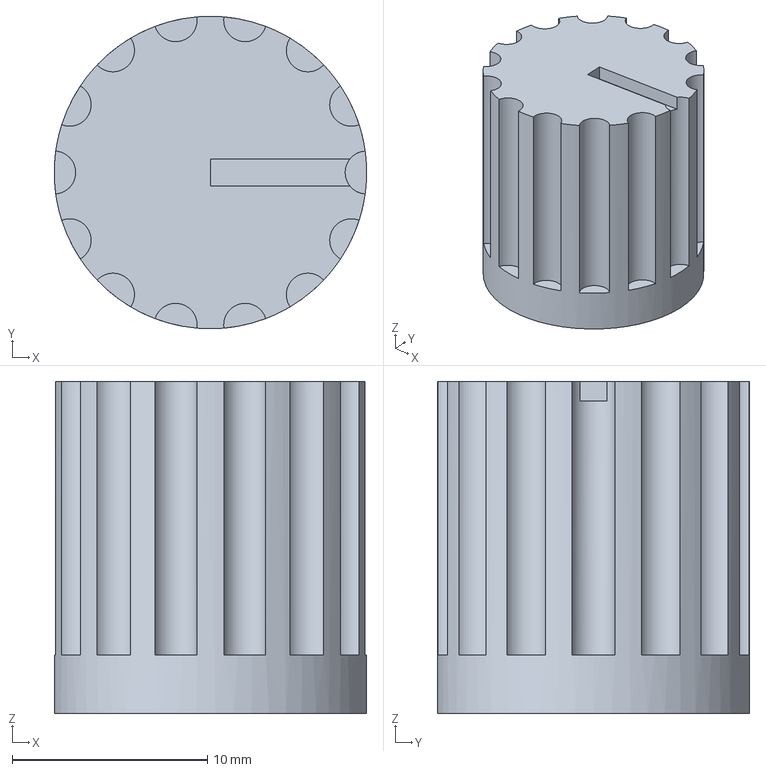
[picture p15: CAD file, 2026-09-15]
cad/encoder_knob.step
16.0 x 16.0 x 17.0 mm

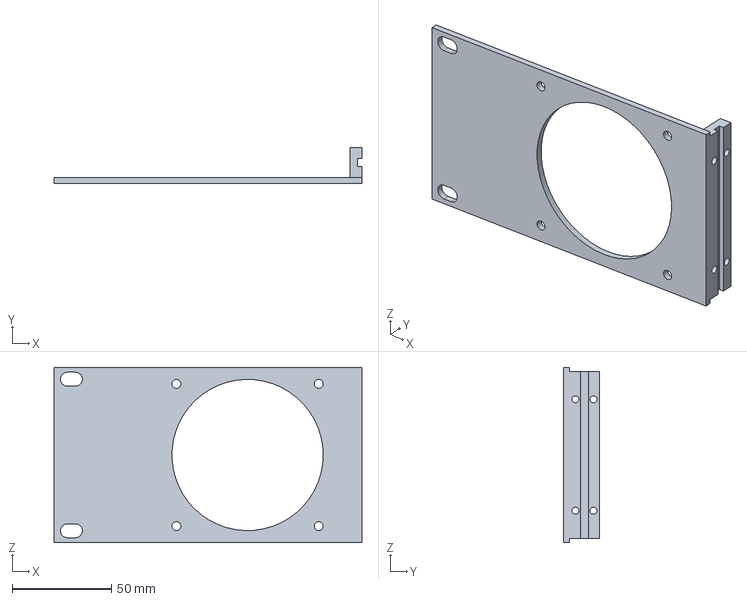
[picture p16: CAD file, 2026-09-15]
cad/seg_left.step
154.8 x 18.0 x 88.1 mm

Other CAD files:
cad/stl/encoder_knob.stl
cad/stl/seg_left.stl
cad/stl/seg_mid.stl
cad/stl/seg_right.stl

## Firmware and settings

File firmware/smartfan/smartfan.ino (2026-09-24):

/*
 * 19" 2U smart temperature-controlled fan -- Arduino UNO R4 WiFi firmware
 * ---------------------------------------------------------------
 * Features:
 *   - 3x 80mm 4-pin PWM fans: 25kHz PWM speed control; PST daisy-chain (only the master fan reports TACH)
 *   - DS18B20 module for temperature (module has an onboard 4.7k pull-up)
 *   - Local closed-loop control (fan curve + slew limiting + failsafe), 4 modes; keeps running during provisioning
 *   - KY-040 rotary encoder: adjust setpoint / cycle pages / switch mode
 *   - 0.96" I2C OLED (SSD1306, 128x64) front-panel display; whole screen blinks on alarm
 *   - WiFi + MQTT to Home Assistant (auto-discovery); HA then bridges to HomeKit
 *   - Setpoint/mode stored in EEPROM, survives power loss
 *
 * Required libraries (install via Library Manager):
 *   ArduinoMqttClient, ArduinoJson, OneWire, DallasTemperature,
 *   Adafruit GFX Library, Adafruit SSD1306, QRCode (Richard Moore)
 *   (WiFiS3 / Wire / pwm.h (PwmOut) / EEPROM / WDT ship with the R4 core)
 *
 * Fan PWM: a single D9 line -> pin 4 of all 3 fans (4-wire fan PWM is a high-impedance input, so one line can be shared, per the Intel 4-wire spec).
 *   By default PwmOut (R4 core, per-pin hardware PWM) drives D9 (=GTIOC7A/GPT7) at a **true 25kHz (silent)**;
 *   only one timer is used, no pin guessing. If you hit problems, set USE_PWMOUT_25K to 0 to fall back to analogWrite (~490Hz, slight whine).
 *   TACH: with the PST daisy-chain only the master fan reports speed, on a single line to D2 (D7/D8 left unused).
 */

#include <WiFiS3.h>
#include <ArduinoMqttClient.h>
#include <ArduinoJson.h>
#include <OneWire.h>
#include <DallasTemperature.h>
#include <EEPROM.h>
#include <Wire.h>
#include <Adafruit_GFX.h>
#include <Adafruit_SSD1306.h>
#include "qrcode.h"                          // provisioning QR code (Library Manager: "QRCode" by Richard Moore)
#include <WDT.h>                             // hardware watchdog (ships with the R4 core)

// ===================== User config =====================
// WiFi / MQTT / device ID are not hardcoded: on first boot (or after reset) the provisioning portal starts --
// the OLED shows a QR code, scan it to join the device's AP, fill in the web form and save (see provisioning section below).
const char* AP_SSID   = "RackFan-Setup";     // provisioning AP name (joined automatically via QR)
const char* AP_PASS   = "configme123";       // provisioning AP password (>=8 chars; embedded in the QR). Default -- change before flashing to keep the setup AP private (anyone nearby can join it during provisioning)
const char* DEVID_DEFAULT = "rackfan01";     // default device ID (editable in the portal)

// ---- Pins ----
const uint8_t FAN_PWM_PIN = 9;             // one PWM line -> pin 4 of all 3 fans (high-Z input, shareable; true 25kHz)
const uint8_t TACH_PIN = 2;                // PST daisy-chain: master fan TACH only (open-collector, internal pull-up); D7/D8 unused
const uint8_t ONEWIRE_PIN = 4;             // DS18B20
const uint8_t ENC_A = 3, ENC_B = 6, ENC_SW = 12;  // KY-040: CLK=D3 (interrupt-capable) / DT=D6 / SW=D12

// ---- Display: 0.96" I2C OLED (SSD1306, 128x64) ----
// Wired to the UNO R4 WiFi's dedicated SDA/SCL pins (onboard Wire); VCC=5V/3V3, GND. Address is usually 0x3C.
#define OLED_W      128
#define OLED_H      64
#define OLED_ADDR   0x3C

// ---- Bench debug switch ----
// 1 = verify the control logic without sensor/fans/encoder/OLED attached:
//     (1) opens 115200 serial, prints temp/duty/RPM/mode/alarm every second
//     (2) simulates temperature with a millis-driven triangle wave (20->65->20, ~60s) and RPM from duty
//        -- sweeps the curve floor / linear region / T_CRIT failsafe, without false stall alarms
// Note: the provisioning portal still runs (not skipped). After first boot/reset, join RackFan-Setup
//       with a phone and complete provisioning; serial output starts only after the reboot into the main loop. Set back to 0 for production.
#define DEBUG_NO_HW    0

// ---- Control parameters (defaults, may be overridden by EEPROM/HA) ----
#define USE_PWMOUT_25K 1                   // 1=PwmOut true 25kHz (default, silent); 0=analogWrite ~490Hz (fallback)
const float T_CRIT   = 60.0f;              // critical temperature -> force 100%
const uint8_t DUTY_FLOOR = 20;             // minimum duty % in auto mode
const uint8_t SILENT_CAP = 60;             // duty cap % in silent mode
const uint16_t STALL_RPM = 60;             // below this counts as stalled
const uint32_t WIFI_BEGIN_WAIT = 2000;     // max ms WiFi.begin() may block the loop (core default 10000)
const uint32_t WIFI_RETRY_MS   = 15000;    // WiFi re-begin interval (long enough for a join to finish in the background)
const uint32_t MQTT_RETRY_MS   = 5000;     // MQTT reconnect interval
const uint32_t MQTT_TCP_WAIT   = 2000;     // max ms for the MQTT TCP connect (WiFiS3 default would wait up to the 10s modem timeout)
const uint32_t MQTT_ACK_WAIT   = 2000;     // max ms to wait for CONNACK; TCP + CONNACK must stay well under WDT_TIMEOUT_MS
// Hardware watchdog: resets the MCU if loop() (or the portal loop) stops running, e.g. the WiFi co-processor hangs.
// RA4M1 max is ~5.59s; every blocking network call above is bounded to <= ~4s and the WDT is refreshed right before it.
const uint32_t WDT_TIMEOUT_MS  = 5500;

enum Mode : uint8_t { AUTO=0, MANUAL=1, SILENT=2, TURBO=3 };
const char* MODE_NAME[4] = {"Auto", "Manual", "Silent", "Turbo"};

// Persistent config
struct Config {
  uint32_t magic;       // validity marker
  float    setpoint;    // target temperature °C (auto-curve midpoint)
  uint8_t  mode;        // Mode
  uint8_t  manualDuty;  // manual duty %
  bool     power;       // on/off
} cfg;
const uint32_t CFG_MAGIC = 0x52464E31;     // "RFN1"

// Network config (WiFi / MQTT / device ID), stored in EEPROM, written by the portal page
struct NetCfg {
  uint32_t magic;
  char ssid[33];      // WiFi SSID
  char pass[65];      // WiFi password
  char host[40];      // MQTT host
  uint16_t port;      // MQTT port
  char user[33];      // MQTT user (empty = anonymous)
  char mpass[33];     // MQTT password
  char devid[24];     // device ID
} netcfg;
const uint32_t NETCFG_MAGIC = 0x4E455431;  // "NET1"
const int      NETCFG_ADDR  = 512;         // EEPROM offset (clear of cfg@0)

// ===================== Global state =====================
WiFiClient   wifiClient;
MqttClient   mqtt(wifiClient);
OneWire      oneWire(ONEWIRE_PIN);
DallasTemperature ds18(&oneWire);
Adafruit_SSD1306 oled(OLED_W, OLED_H, &Wire, -1);

float   g_temp = NAN;          // current temperature
uint8_t g_duty = 0;            // current duty %
uint16_t g_rpm = 0;            // master fan RPM (single PST line)
volatile uint32_t g_pulses = 0;
bool    g_alarm = false;
const char* g_alarmMsg = "";
uint8_t g_page = 0;            // encoder-selected item: 0 temp, 1 setpoint, 2 fan %, 3 mode (for the big-text edit hint)
uint32_t g_uiTouch = 0;        // time of last encoder action (edit hint display window)

// Task timers
uint32_t tSample=0, tDisplay=0, tMqtt=0, tReconnect=0;

// ===================== TACH interrupt =====================
void isr0(){ g_pulses++; }                 // single PST TACH (master fan)

// ===================== Fan PWM (single D9 line, split to 3 fans) =====================
#if USE_PWMOUT_25K
#include "pwm.h"                        // R4 core: per-pin hardware PWM (PwmOut -> D9=GTIOC7A/GPT7)
PwmOut fanPwm(FAN_PWM_PIN);
void pwmBegin() { fanPwm.begin(25000.0f, 0.0f); }                 // true 25kHz (silent), start at 0%
void pwmSet(uint8_t duty) { fanPwm.pulse_perc(constrain((float)duty, 0.0f, 100.0f)); }  // 0..100 %
#else
void pwmBegin() { pinMode(FAN_PWM_PIN, OUTPUT); analogWrite(FAN_PWM_PIN, 0); }  // fallback: analogWrite ~490Hz
void pwmSet(uint8_t duty) { analogWrite(FAN_PWM_PIN, map(constrain(duty,0,100), 0, 100, 0, 255)); }
#endif

// ===================== EEPROM =====================
void cfgLoad() {
  EEPROM.get(0, cfg);
  if (cfg.magic != CFG_MAGIC) {        // first boot: write defaults
    cfg.magic = CFG_MAGIC;
    cfg.setpoint = 35.0f; cfg.mode = AUTO; cfg.manualDuty = 50; cfg.power = true;
    EEPROM.put(0, cfg);
  }
  // Sanitize: a corrupt EEPROM must not index MODE_NAME out of range or yield a NaN setpoint
  if (cfg.mode > TURBO) cfg.mode = AUTO;
  if (isnan(cfg.setpoint) || cfg.setpoint < 25 || cfg.setpoint > 55) cfg.setpoint = 35.0f;
  if (cfg.manualDuty > 100) cfg.manualDuty = 50;
}
// Deferred save: knob detents / HA commands only mark the config dirty; it is written once,
// CFG_SAVE_DELAY ms after the last change (spinning the knob no longer writes EEPROM per detent).
const uint32_t CFG_SAVE_DELAY = 3000;
bool     g_cfgDirty = false;
uint32_t g_cfgDirtyAt = 0;
void cfgSave() { g_cfgDirty = true; g_cfgDirtyAt = millis(); }
void cfgSaveStep() {
  if (g_cfgDirty && millis() - g_cfgDirtyAt >= CFG_SAVE_DELAY) { EEPROM.put(0, cfg); g_cfgDirty = false; }
}

// ===================== Control core =====================
uint8_t curveDuty(float t) {           // fan curve: Tset-10 -> floor, Tset+6 -> 100
  float lo = cfg.setpoint - 10.0f, hi = cfg.setpoint + 6.0f;
  if (isnan(t))      return 100;       // sensor failure -> full speed
  if (t <= lo)       return DUTY_FLOOR;
  if (t >= hi)       return 100;
  return (uint8_t)(DUTY_FLOOR + (t - lo) * (100 - DUTY_FLOOR) / (hi - lo));
}

void controlStep() {
  // 1) Safety: critical temp / sensor failure -> force 100%
  bool overTemp = (!isnan(g_temp) && g_temp >= T_CRIT);
  bool sensorBad = isnan(g_temp) || g_temp < -50 || g_temp > 125;

  uint8_t target;
  if (!cfg.power) {
    target = 0;
  } else if (overTemp || sensorBad) {
    target = 100;
  } else {
    switch (cfg.mode) {
      case MANUAL: target = cfg.manualDuty; break;
      case TURBO:  target = 100; break;
      case SILENT: { uint8_t c = curveDuty(g_temp); target = (c < SILENT_CAP) ? c : SILENT_CAP; break; }
      case AUTO:
      default:     target = curveDuty(g_temp); break;
    }
  }

  // 2) Slew-rate limit (max 5% per step) to avoid duty jumps; the curve slope itself provides hysteresis
  const int step = 5;
  if (target > g_duty)      g_duty += (target - g_duty > step) ? step : (target - g_duty);
  else if (target < g_duty) g_duty -= (g_duty - target > step) ? step : (g_duty - target);
  pwmSet(g_duty);

  // 3) Alarms: over-temp / sensor failure / stall (driven but no RPM)
  bool stall = false;
  if (cfg.power && g_duty > 25) {
    if (g_rpm < STALL_RPM) stall = true;     // PST: only the master fan is measurable; the other two have no own TACH
  }
  g_alarm = overTemp || sensorBad || stall;
  g_alarmMsg = overTemp ? "OVERTEMP" : sensorBad ? "SENSOR" : stall ? "STALL" : "";
}

// ===================== Bench debug (no peripherals) =====================
#if DEBUG_NO_HW
// Triangle-wave temperature: 20->65->20, ~60s period. Covers the curve floor (<=Tset-10) / linear region /
// full-speed region (>=Tset+6) / failsafe (>=T_CRIT=60). RPM simulated from duty, >STALL_RPM to avoid false stall alarms.
void simSensors() {
  const float TMIN = 20.0f, TMAX = 65.0f, PERIOD = 60000.0f;
  float ph  = fmod((float)millis(), PERIOD) / PERIOD;            // 0..1
  float tri = (ph < 0.5f) ? (ph * 2.0f) : (2.0f - ph * 2.0f);    // 0..1..0
  g_temp = TMIN + (TMAX - TMIN) * tri;
  g_rpm = (g_duty > 0) ? (uint16_t)(g_duty * 18) : 0;           // 0..1800 rpm
}
void dbgPrint() {
  Serial.print("T=");      Serial.print(g_temp, 1);
  Serial.print("C  duty="); Serial.print(g_duty);
  Serial.print("%  rpm=");  Serial.print(g_rpm);
  Serial.print("  mode=");  Serial.print(MODE_NAME[cfg.mode]);
  Serial.print("  power="); Serial.print(cfg.power ? "ON" : "OFF");
  Serial.print("  alarm="); Serial.println(g_alarm ? g_alarmMsg : "none");
}
#endif

// ===================== Sampling =====================
void sampleStep() {
  // Temperature
  ds18.requestTemperatures();
  float t = ds18.getTempCByIndex(0);
  g_temp = (t == DEVICE_DISCONNECTED_C) ? NAN : t;
  // RPM: pulses/s -> RPM (2 pulses/rev); with PST only the master fan has TACH
  noInterrupts();
  uint32_t p = g_pulses; g_pulses = 0;
  interrupts();
  g_rpm = (uint16_t)(p * 30);   // /2*60
#if DEBUG_NO_HW
  simSensors();                            // no peripherals: overwrite real readings with simulated values
#endif
}

// ===================== Display (0.96" OLED, SSD1306) =====================
// Product-style layout: top = WiFi signal + mode, middle = large temperature (thermometer icon), bottom = master fan RPM (fan icon).
// For 2.5s after an encoder action, the big middle text temporarily shows the edited item (setpoint/fan %/mode) as "blind-adjust" feedback.
static void drawThermo(int x, int y) {            // small thermometer icon (tube top at y)
  oled.drawRect(x - 2, y, 5, 13, SSD1306_WHITE);        // tube
  oled.fillRect(x - 1, y + 6, 3, 9, SSD1306_WHITE);     // mercury
  oled.fillCircle(x, y + 15, 4, SSD1306_WHITE);         // bulb
}
static void drawFanIcon(int cx, int cy) {         // small fan icon (center, radius 5)
  oled.drawCircle(cx, cy, 5, SSD1306_WHITE);
  oled.fillCircle(cx, cy, 1, SSD1306_WHITE);
  oled.drawLine(cx, cy, cx + 3, cy - 3, SSD1306_WHITE);
  oled.drawLine(cx, cy, cx - 3, cy + 3, SSD1306_WHITE);
  oled.drawLine(cx, cy, cx + 3, cy + 2, SSD1306_WHITE);
}
static void drawDeg(int x, int y) { oled.drawCircle(x, y, 2, SSD1306_WHITE); }   // degree symbol

void drawSplash(const char* s) {
  oled.clearDisplay();
  oled.setTextColor(SSD1306_WHITE);
  oled.setTextSize(2);
  oled.setCursor(0, 24);
  oled.print(s);
  oled.display();
}
void displayStep() {
  static bool blink = false; blink = !blink;
  oled.clearDisplay();
  if (g_alarm && blink) { oled.display(); return; }   // alarm: blink whole screen
  oled.setTextColor(SSD1306_WHITE);

  // ---- Top bar: WiFi signal (left) + alarm badge + mode (right) ----
  bool wok = (WiFi.status() == WL_CONNECTED);
  int rssi = wok ? WiFi.RSSI() : -127;
  int nb = !wok ? 0 : rssi >= -55 ? 4 : rssi >= -67 ? 3 : rssi >= -78 ? 2 : 1;
  for (int i = 0; i < 4; i++) {
    int bx = 2 + i * 4, bh = 3 + i * 2, by = 12 - bh;
    if (i < nb) oled.fillRect(bx, by, 3, bh, SSD1306_WHITE);
    else        oled.drawRect(bx, by, 3, bh, SSD1306_WHITE);
  }
  oled.setTextSize(1);
  if (!wok)    { oled.setCursor(21, 4); oled.print("x"); }       // not connected
  if (g_alarm) { oled.setCursor(40, 4); oled.print("ALM"); }
  const char* mn = MODE_NAME[cfg.mode];
  oled.setCursor(128 - (int)strlen(mn) * 6, 4); oled.print(mn);
  oled.drawFastHLine(0, 15, 128, SSD1306_WHITE);

  // ---- Middle big text: default = current temp; for 2.5s after an encoder action = edited item ----
  bool editing = g_uiTouch && (millis() - g_uiTouch < 2500) && g_page != 0;
  if (editing) {
    // Edit hint sits upper-middle in 2x font, **without crowding the bottom status row** (RPM/% stay visible)
    const char* tag = (g_page == 1) ? "SET" : (g_page == 2) ? "FAN" : "MODE";
    oled.setTextSize(1); oled.setCursor(6, 17); oled.print(tag);
    oled.setTextSize(2);
    if (g_page == 3) {                                           // mode name
      oled.setCursor(6, 27); oled.print(MODE_NAME[cfg.mode]);
    } else if (g_page == 1) {                                    // setpoint
      int v = (int)round(cfg.setpoint);
      oled.setCursor(6, 27); oled.print(v);
      int ex = 6 + (v >= 100 ? 3 : v >= 10 ? 2 : 1) * 12;
      drawDeg(ex + 2, 29); oled.setCursor(ex + 6, 27); oled.print("C");
    } else {                                                     // fan %
      // Manual mode: show the value being dialed in (cfg.manualDuty), not g_duty, which is still slewing toward it at 5%/s
      int v = (cfg.mode == MANUAL) ? cfg.manualDuty : g_duty;
      oled.setCursor(6, 27); oled.print(v);
      int ex = 6 + (v >= 100 ? 3 : v >= 10 ? 2 : 1) * 12;
      oled.setCursor(ex + 2, 27); oled.print("%");
    }
  } else {
    drawThermo(8, 22);
    oled.setTextSize(3); oled.setCursor(22, 22);
    if (isnan(g_temp)) { oled.print("--"); }
    else {
      oled.print(g_temp, 1);                                      // one decimal, e.g. 26.8
      int digits = (g_temp >= 100) ? 5 : (g_temp >= 10) ? 4 : 3; // char count incl. decimal point
      int ex = 22 + digits * 18;
      drawDeg(ex + 3, 25);
      oled.setTextSize(2); oled.setCursor(ex + 8, 28); oled.print("C");
    }
  }

  // ---- Bottom: master fan RPM (fan icon, left) + current duty (right) ----
  drawFanIcon(8, 56);
  int rpm = g_rpm;
  oled.setTextSize(1); oled.setCursor(20, 53); oled.print(rpm); oled.print(" RPM");
  char ds[8]; snprintf(ds, sizeof(ds), "%d%%", g_duty);
  oled.setCursor(128 - (int)strlen(ds) * 6, 53); oled.print(ds);

  oled.display();
}

// ===================== KY-040 encoder =====================
// CLK on D3 (on the R4 WiFi only D2/D3 officially support external interrupts; D2 is taken by TACH, so the encoder uses D3).
// The ISR reads DT on the CLK falling edge to get direction -- unaffected by OLED/MQTT time spent in loop, no missed steps, correct direction.
// (Previously CLK on D5 with attachInterrupt never fired; polling instead missed steps -- hence the move to D3 with an interrupt.)
volatile int8_t g_encDelta = 0;
void encISR() {                       // on CLK falling edge read DT for direction (swap +1/-1 if reversed)
  static uint32_t lastMs = 0;
  uint32_t now = millis();
  if (now - lastMs < 5) return;       // debounce: ignore bounce edges within 5ms (one count per detent)
  lastMs = now;
  g_encDelta += (digitalRead(ENC_B) ? +1 : -1);
}
void encoderStep() {
  // Rotate: manual mode -> adjust fan % (±5); other modes -> adjust setpoint (±1)
  if (g_encDelta != 0) {
    noInterrupts(); int8_t d = g_encDelta; g_encDelta = 0; interrupts();
    if (cfg.mode == MANUAL) {
      cfg.manualDuty = constrain(cfg.manualDuty + d * 5, 0, 100);
      g_page = 2;                       // jump to "fan %" page
    } else {
      cfg.setpoint = constrain((int)cfg.setpoint + d, 25, 55);
      g_page = 1;                       // jump to "setpoint" page
    }
    g_uiTouch = millis();               // trigger edit hint (big text temporarily shows edited item)
    cfgSave(); mqttPublishState();
  }
  // Button: short press cycles page; long press switches mode
  static bool last = HIGH; static uint32_t tDown=0; static bool longDone=false;
  bool now = digitalRead(ENC_SW);
  if (last==HIGH && now==LOW) { tDown=millis(); longDone=false; }
  if (now==LOW && !longDone && millis()-tDown>800) {   // long press -> switch mode
    cfg.mode = (cfg.mode + 1) & 3; longDone=true; cfgSave(); g_page=3; g_uiTouch=millis(); mqttPublishState();
  }
  if (last==LOW && now==HIGH) {                          // release -> short press cycles page
    if (!longDone) { g_page = (g_page + 1) & 3; g_uiTouch = millis(); }
  }
  last = now;
}

// ===================== MQTT (Home Assistant auto-discovery) =====================
String baseT() { return String("rackfan/") + netcfg.devid; }   // state/command topic prefix
// Availability: retained "online" after connect; the broker publishes the retained LWT "offline" when the device drops,
// so HA greys the entities out instead of showing stale retained values forever.
String availT() { return baseT() + "/avail"; }
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
void loop() {
  WDT.refresh();
  uint32_t now = millis();

  encoderStep();                         // encoder (handled every iteration for responsiveness)

  if (now - tSample >= 1000) {           // sample + control at 1Hz
    tSample = now;
    sampleStep();
    controlStep();
#if DEBUG_NO_HW
    dbgPrint();
#endif
  }
  if (now - tDisplay >= 250) {           // display at 4Hz
    tDisplay = now;
    displayStep();
  }
  if (now - tMqtt >= 2000) {             // MQTT state at 0.5Hz
    tMqtt = now;
    if (mqtt.connected()) mqttPublishState();
  }
  cfgSaveStep();                         // deferred EEPROM write
  // Reconnect: check WiFi status directly (don't wait for the MQTT keepalive timeout). WiFi is re-begun every
  // WIFI_RETRY_MS so a join in progress isn't restarted; MQTT is retried every MQTT_RETRY_MS once WiFi is up.
  bool wifiUp = (WiFi.status() == WL_CONNECTED);
  if ((!wifiUp || !mqtt.connected()) && now - tReconnect >= (wifiUp ? MQTT_RETRY_MS : WIFI_RETRY_MS)) {
    tReconnect = now;
    WDT.refresh();                            // WiFi.begin / mqttConnect below block for up to ~2s / ~4s
    if (!wifiUp) {
      WiFi.setHostname(netcfg.devid);        // keep the custom hostname on reconnect too
      WiFi.begin(netcfg.ssid, netcfg.pass);  // WiFi dropped -> reconnect; rejoins automatically once the network is back (temperature control unaffected throughout)
    } else {
      mqttConnect();                          // WiFi up, only MQTT down -> reconnect MQTT (and resend auto-discovery)
    }
  }
  if (mqtt.connected()) mqtt.poll();     // process subscribed messages
}

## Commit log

2026-09-15 Initial open-source release: 19" 2U smart temperature-controlled rack fan
    Arduino UNO R4 WiFi firmware, parametric build123d CAD (3D-printed
    panel + knob), wiring diagrams, and Home Assistant / HomeKit integration.
    English docs with Simplified Chinese translations. MIT licensed.
    [encoder_knob.step, encoder_knob.stl, rack_fan_2u.step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]
2026-09-15 Switch English README BOM to Amazon US links
    Replace Taobao links/CNY prices in README.md with Amazon US listings and
    approximate USD prices; zh-CN README keeps Taobao links. Add a note that
    printed mounts were sized on the original modules (check footprints).
2026-09-24 Firmware: watchdog, MQTT availability (LWT), manual-% edit display; doc fixes
    - Add a ~5.5s hardware watchdog (R4 core WDT) refreshed in loop() and the
    portal loop; bound the MQTT TCP connect (2s) and CONNACK wait (2s) so no
    blocking network call can trip it. After a watchdog reset the duty starts
    at 100% and slews down, so a reset loop still keeps the cabinet cooled.
    - Publish availability on rackfan/<id>/avail: retained "online" after
    connect plus an "offline" LWT; every discovery entity carries avty_t, and
    the manual YAML fallback gets availability_topic.
    - In Manual mode the knob edit hint now shows the target manual % instead
    of the still-slewing actual duty.
    - README (EN +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
    [smartfan.ino]
